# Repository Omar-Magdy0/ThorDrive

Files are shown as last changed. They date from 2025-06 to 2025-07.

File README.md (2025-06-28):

---
# ⚡ ThorDrive

A modular, open-source platform for developing **inverters**, **controllers**, and **embedded firmware** for electric vehicle applications.  
Built with robust engineering principles and driven by passion.

Maintained by **Omar Magdy** for the **Cairo University Eco Racing Team**.

---

## 🧠 Overview

ThorDrive implements a range of hardware and software solutions for electric drive systems.  
It includes:

- Custom inverters (multi-phase and bidirectional support)
- Firmware for Trapezoidal , FOC, SPWM, SVM, and advanced motor control
- Modular controllers and drivers
- Fully documented software and hardware stacks
- Design iterations built for real-world racing

---

## 🚀 Features

- ⚙️ **Multiple Inverter Designs**
- 🧾 **Well-documented Firmware** using Doxygen
- 💡 **Modular & Scalable Design** across generations
- 🛠️ **Interactive BOMs and Fabrication-Ready Gerbers**
- 🔧 **Configurable Build System** for firmware
- 💻 **Simulator & HIL Support**
- 🧪 **Validated by Real-World Team Use**

Specific features are documented in each design subfolder:

## 🛠️ Get Started

1. **Navigate to a Design Folder**  
   Visit:
   - `ThorDrive_FW/<DesignName_and_Version>/README.md`
   - `ThorDrive_HW/<DesignName_and_Version>/README.md`

2. **Build Software / Flash Firmware**  
   Follow platform-specific build instructions in each firmware README.

3. **Hardware Fabrication**  
   - Use provided **Gerber** files for PCB manufacturing.
   - Access **Interactive BOM** from each hardware directory.

---

## 📚 Documentation

- **Firmware Documentation (Doxygen)**  
  Inside:  
  `ThorDrive_FW/<DesignName_and_Version>/docs/index.html`

- **Hardware Documentation**  
  - Inverter: `ThorDrive_HW/<DesignName_and_Version>/Inverter/Docs/`
  - Controller: `ThorDrive_HW/<DesignName_and_Version>/Controller/Docs/`

---

## 📦 Installation

- Build your own firmware using the instructions in each firmware folder.
- Or, download the **precompiled binaries** from the design folders.
- Configure and flash using the README-provided instructions.

---

## 🧑‍💻 Used By

- 🏁 **Cairo University Eco Racing Team** https://cu-eco.org

---

## 📄 License

This project is open source.  
📌 **License**:  MIT

---

## 💬 Support

You can support the project by:

- Contributing firmware or hardware improvements
- Reviewing documentation and build systems
- Participating in issue tracking and pull requests
- Providing feedback based on hardware tests
- Become a sponsor
---

## 🤝 Sponsors

- 🐚 **Shell**
- ✈️ **EgyptAir**

---

## 📬 Contact

Maintainer: **Omar Magdy**  
📧 [omar.magdy.om.om@gmail.com](mailto:omar.magdy.om.om@gmail.com)

---

## 🏷️ Acknowledgements

- All engineers and contributors from the Cairo University Eco Racing Team

---

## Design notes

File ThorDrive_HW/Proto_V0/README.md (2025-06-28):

📁 `Controller`

# 🧠 BLDC Controller Board

---

## 🔁 Version & Overview

* **Version:** `v1.0`
* **Microcontroller:** `ATmega328P`
* **Designed using:** `KiCad`

The controller board enables BLDC motor control using ATmega328P and supports BEMF zero-crossing sensorless operation.

---

## 🔧 Features

* Sensorless BLDC drive (BEMF zero crossing)
* UART debugging
* Modular firmware architecture
* Supports 3.3V and 5V I/O
* Optimized for low-cost, compact embedded motor controllers
* Single-layer board with minimal top jumpers

#### Notes 
Remove onBoard Potentiometer if going to install external Potentiometer

---

## 🖼️ Hardware Preview
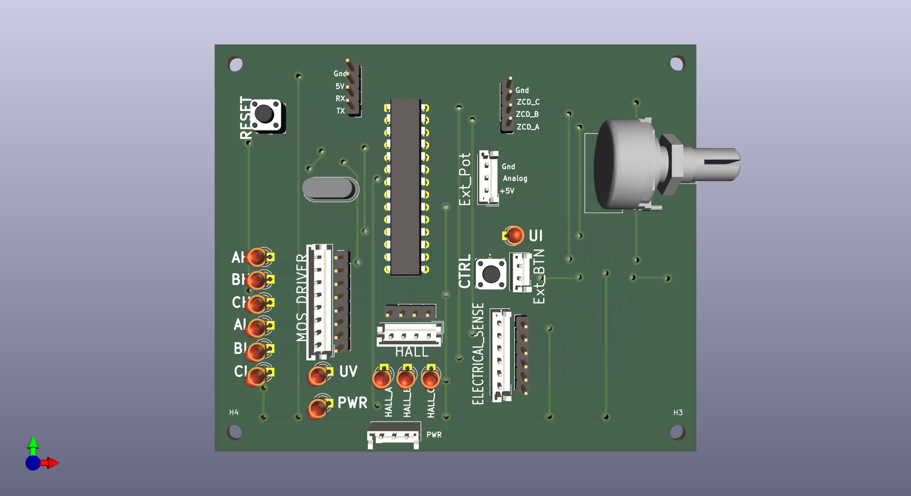
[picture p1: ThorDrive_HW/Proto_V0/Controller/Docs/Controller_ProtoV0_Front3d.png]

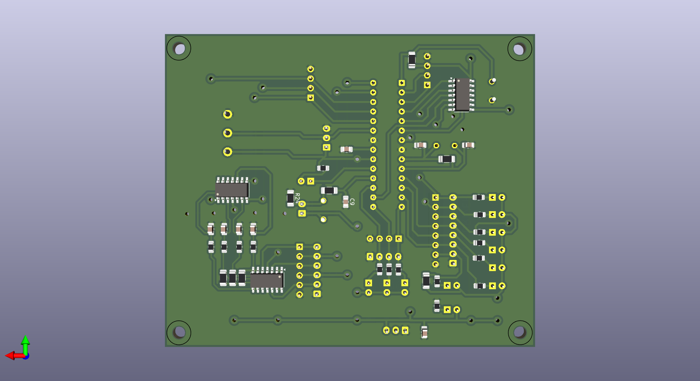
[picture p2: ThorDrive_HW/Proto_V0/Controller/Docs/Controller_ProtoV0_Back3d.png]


---

## 📁 Documentation

| Type | Path |
| --- | --- |
| 🧩 3D Model | `./Controller/Docs/*.step` |
| 📝 Schematic | `./Controller/Docs/*.pdf`  |
| 📂 Design Files | `./Controller` |

### 🌐 Embedded 3D Viewer (STEP)

Try with: [https://3dviewer.net/](https://3dviewer.net/)
Upload: [`./Controller/Docs/*.step`](./Docs)

---

📁 `Inverter`

# ⚡ BLDC Inverter Board

---

## 🔁 Version & Overview

* **Version:** `v1.0`
* **Designed using:** `KiCad`
* **Power Rating:** `2KW+`
* **MOSFET Driver:** `IR2130`

---

## 🔧 Features

### ✅ Phase Voltage Feedback

* Each phase is conditioned via:

  $V_{cond} = V_{phase-ground} \times \left(\frac{2.2k}{49.2k}\right)$

* Filtered with **80kHz low-pass**

* Calibrate as needed due to resistor tolerances

### ✅ Line Current Feedback (ACS712-30A)

* For Phase A & B:

  $V_{cond} = \left( I_{line} \times 66\text{mV} + 2.5 \right) \times \left(\frac{5.1k}{15.1k}\right)$

* Filtered with **80kHz low-pass**

* Calibrate as needed due to resistor tolerances

### ✅ &#x20;General Specs

* 3.3V signal compatible
* Switching frequency up to **20kHz**
* Driver with built-in **dead time** (IR2130)
* 🌡️ **Thermal Management**: Adequate spacing for heat sinks
* Single-layer board with minimal top jumpers

---

## 🖼️ Hardware Preview

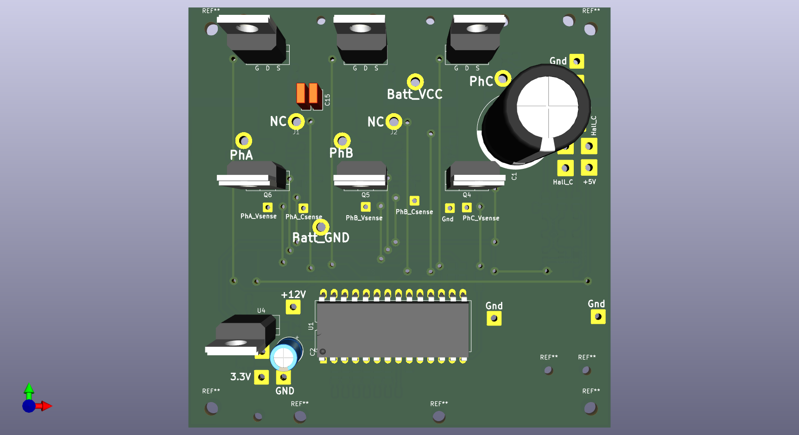
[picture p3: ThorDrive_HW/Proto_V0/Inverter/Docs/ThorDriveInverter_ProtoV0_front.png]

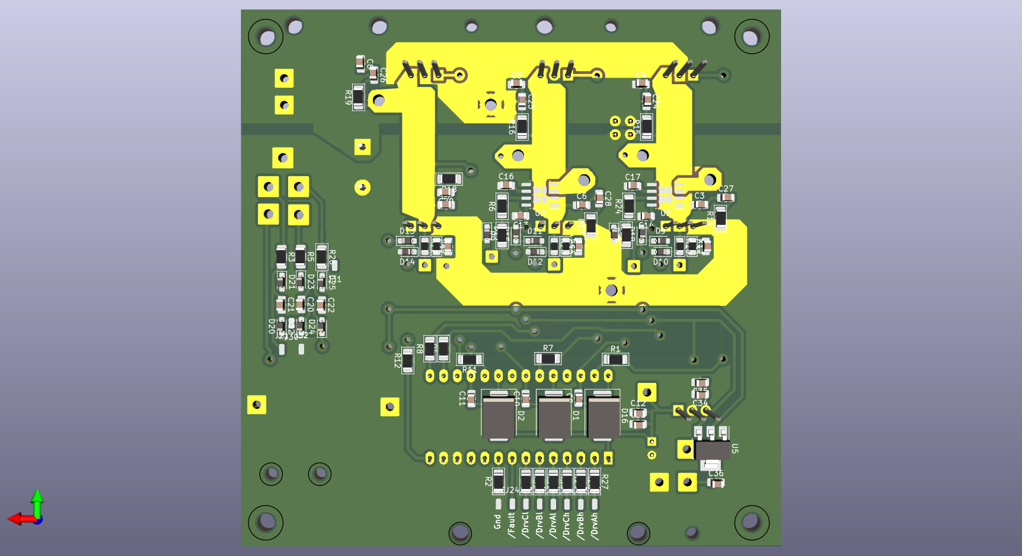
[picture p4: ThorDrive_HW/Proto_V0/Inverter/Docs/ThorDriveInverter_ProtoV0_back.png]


---

## 📁 Documentation

| Type | Path |
| --- | --- |
| 🧩 3D Model | `./Inverter/Docs/*.step` |
| 📝 Schematic | `./Inverter/Docs/*.pdf`  |
| 📂 Design Files | `./Inverter` |

### 🌐 Embedded 3D Viewer (STEP)

Try with: [https://3dviewer.net/](https://3dviewer.net/)
Upload: [`Docs/*.step`](./Docs)

---

## 🔌 Connector Layout & Wiring
Proper connector pin labeling is essential for integration with other subsystems (sensors, MCU, battery, etc.). Images and pinout illustrations will help ensure correct assembly.

### 📷 Visual Reference
 #### 📍 Connector Numbering Reference
<!-- Replace with your actual images -->
**JST**
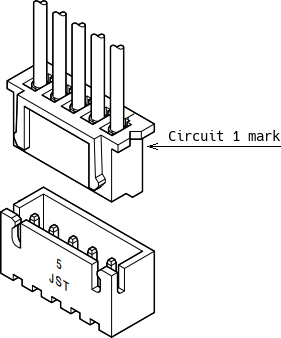
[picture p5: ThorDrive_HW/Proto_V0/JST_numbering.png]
JST Numbering Reference


**Molex**
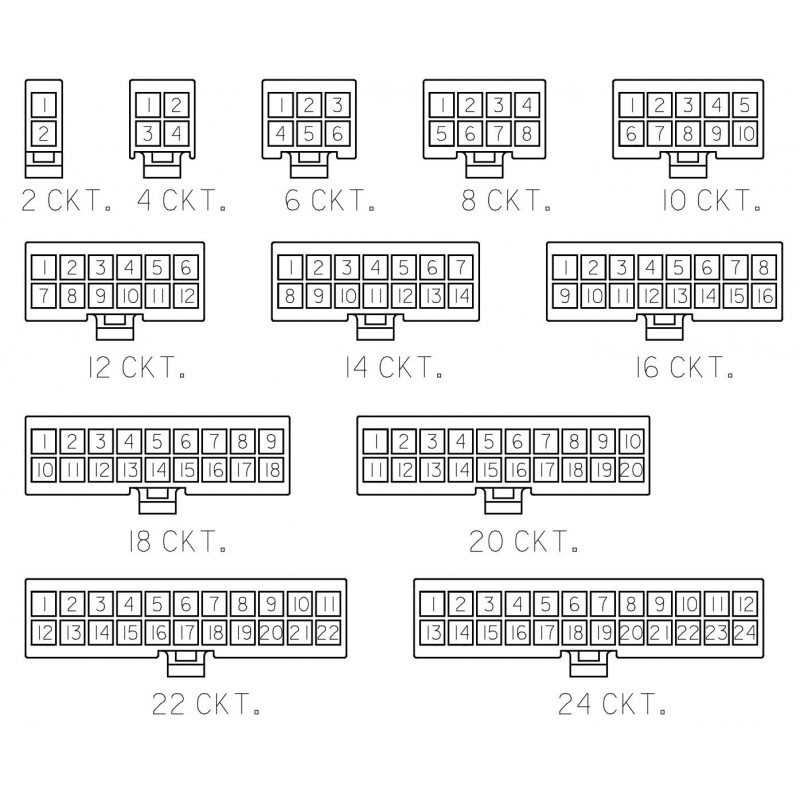
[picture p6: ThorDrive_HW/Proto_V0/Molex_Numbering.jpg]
Molex Numbering Reference


🔌 Sample Harness:  

Controller_Board
---

## 📜 License

This project is licensed under the **MIT License**.
---

## 📬 Contact

Maintainer: **Omar Magdy**
📧 [omar.magdy.om.om@gmail.com](mailto:omar.magdy.om.om@gmail.com)

---

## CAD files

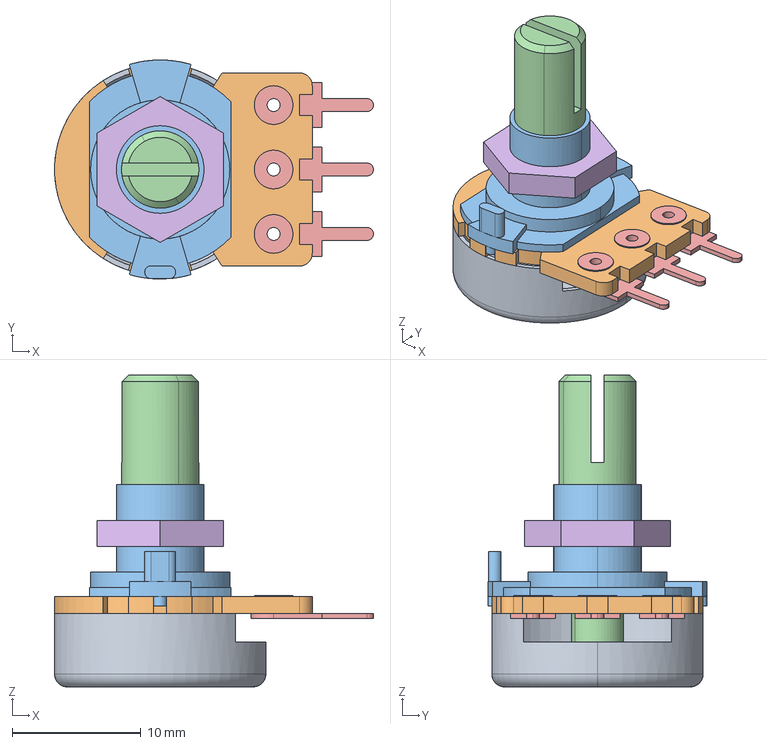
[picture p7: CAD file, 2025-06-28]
ThorDrive_HW/Proto_V0/Controller/LibMain/3d/POT.stp
24.8 x 17.0 x 24.2 mm

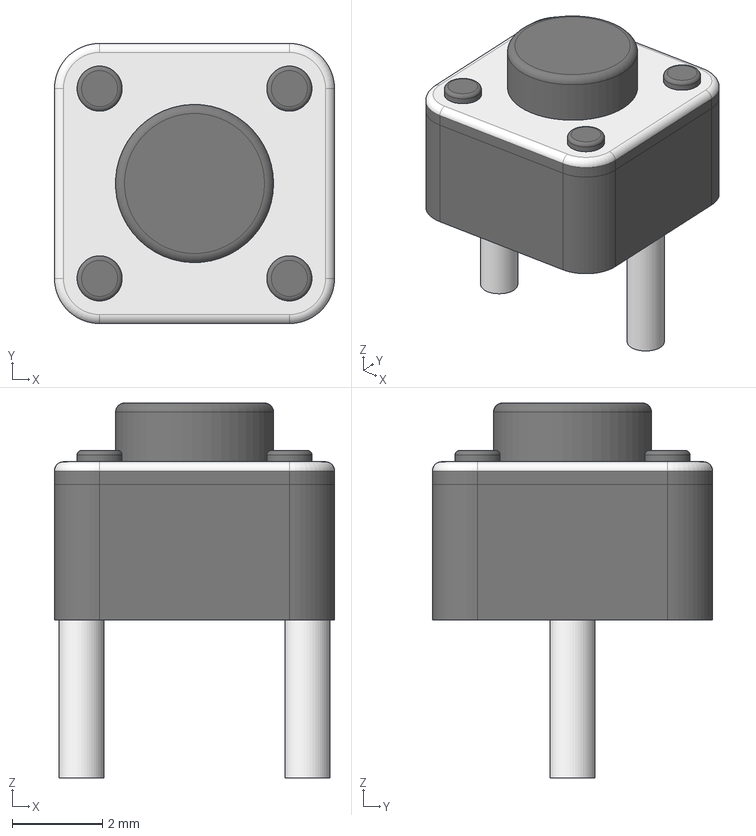
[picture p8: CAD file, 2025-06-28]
ThorDrive_HW/Proto_V0/Controller/LibMain/3d/boton.step
6.20 x 6.20 x 8.30 mm

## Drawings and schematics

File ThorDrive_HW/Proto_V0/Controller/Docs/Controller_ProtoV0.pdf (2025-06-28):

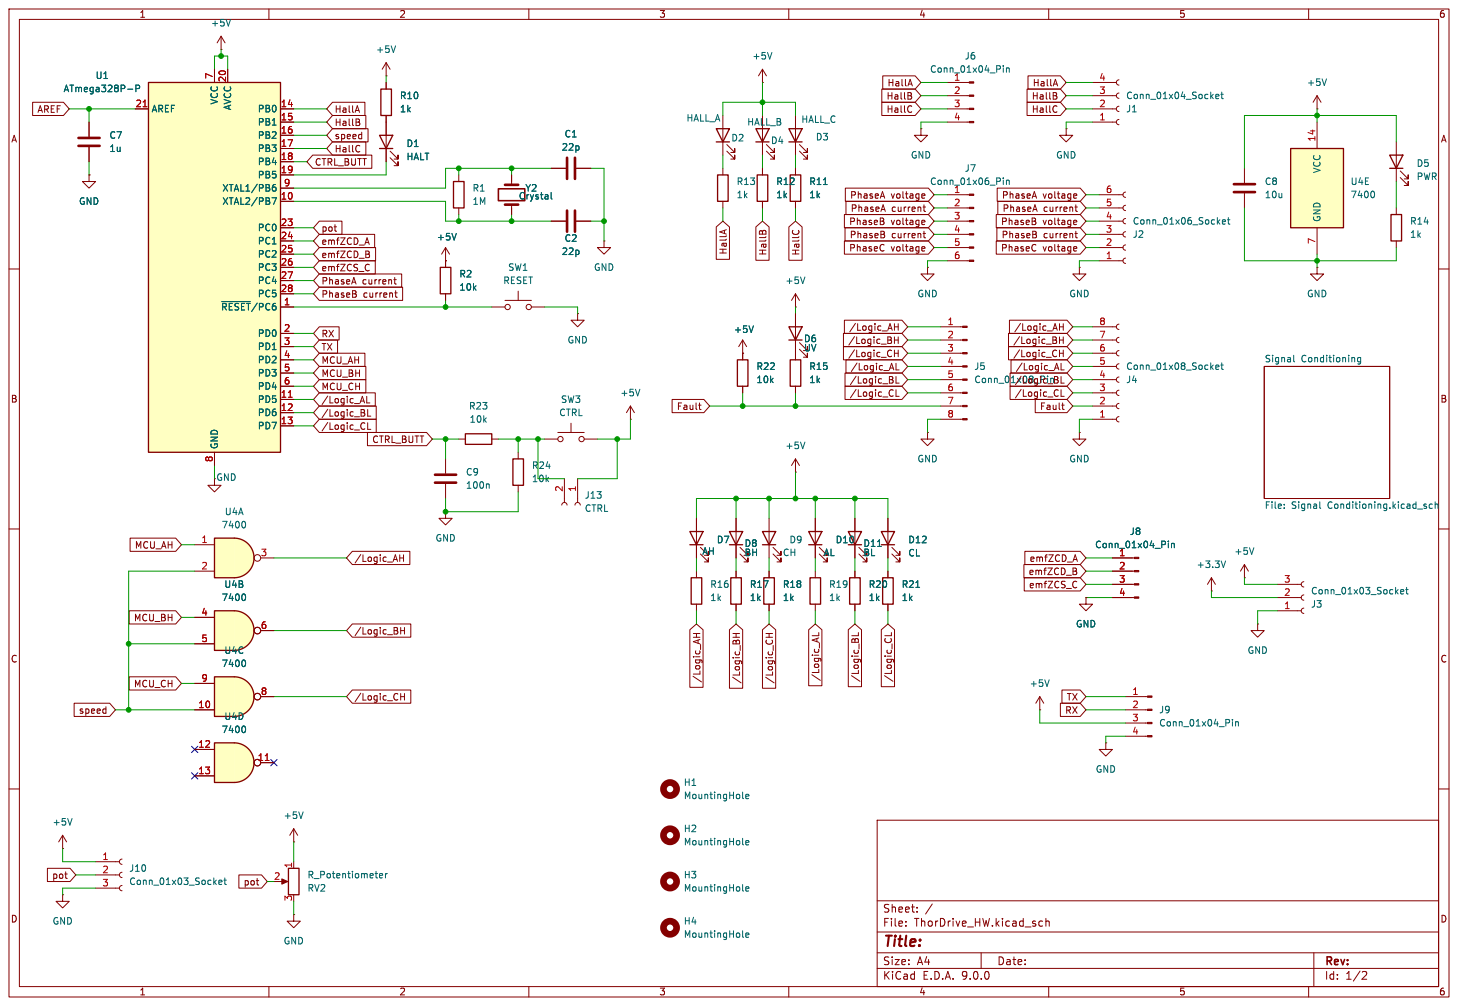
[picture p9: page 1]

HallC
PhaseC voltage PhaseB current CTRL_BUTT

J4Conn_01x08_Socket +5V H3 MountingHole H1 MountingHole H2 MountingHole H4 MountingHole

Signal Conditioning File: Signal Conditioning.kicad_sch

Id: 1/2 Title: File: ThorDrive_HW.kicad_sch Sheet: /

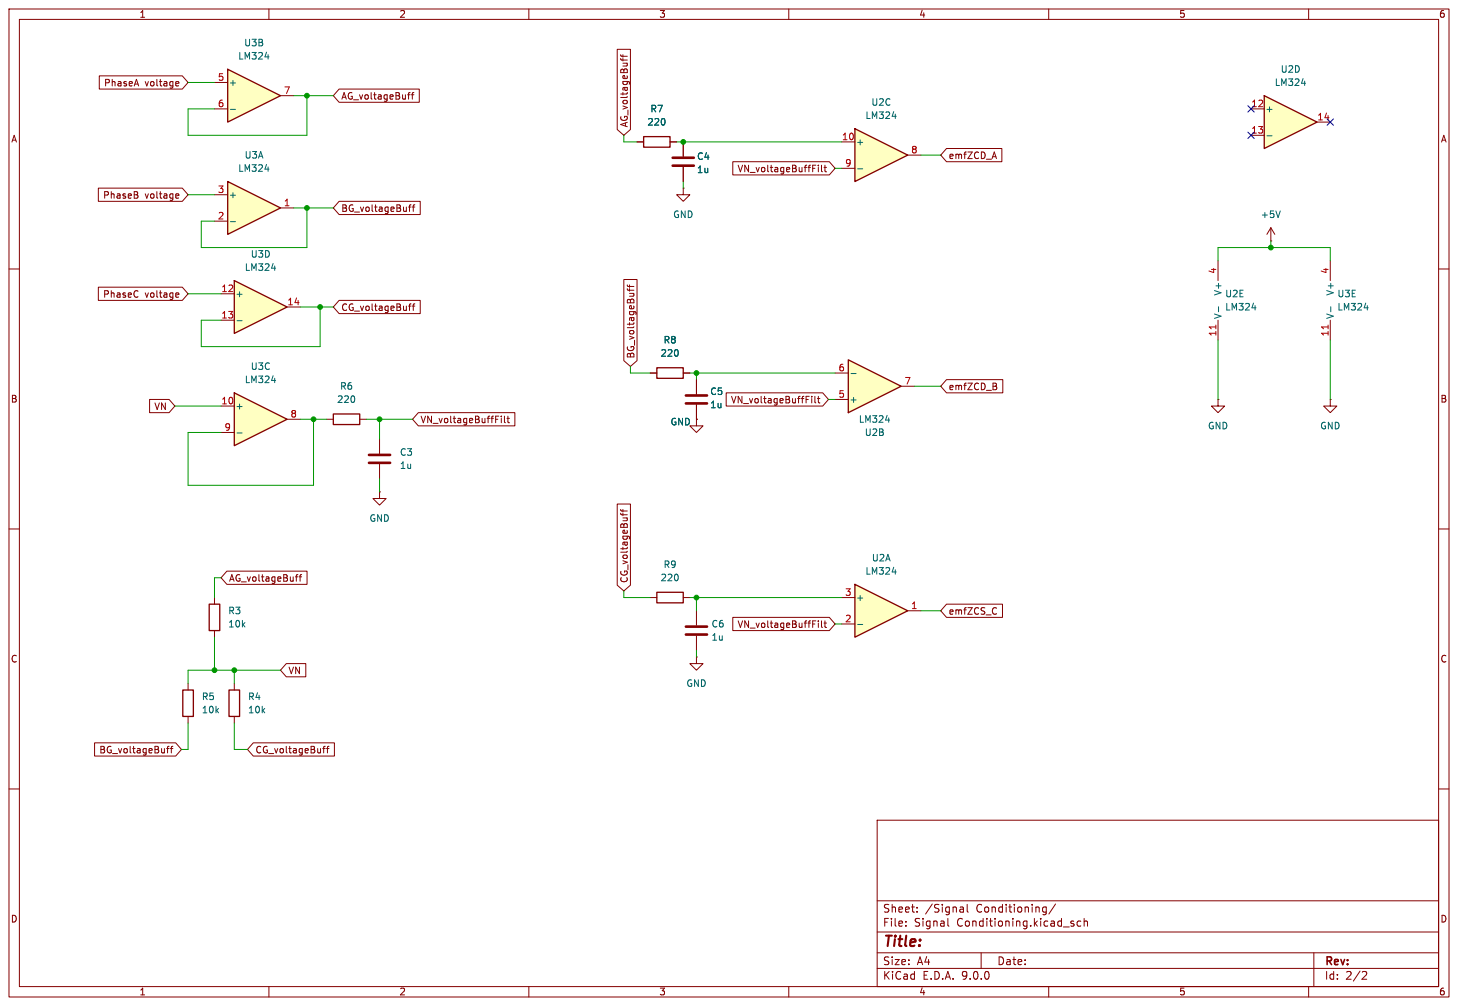
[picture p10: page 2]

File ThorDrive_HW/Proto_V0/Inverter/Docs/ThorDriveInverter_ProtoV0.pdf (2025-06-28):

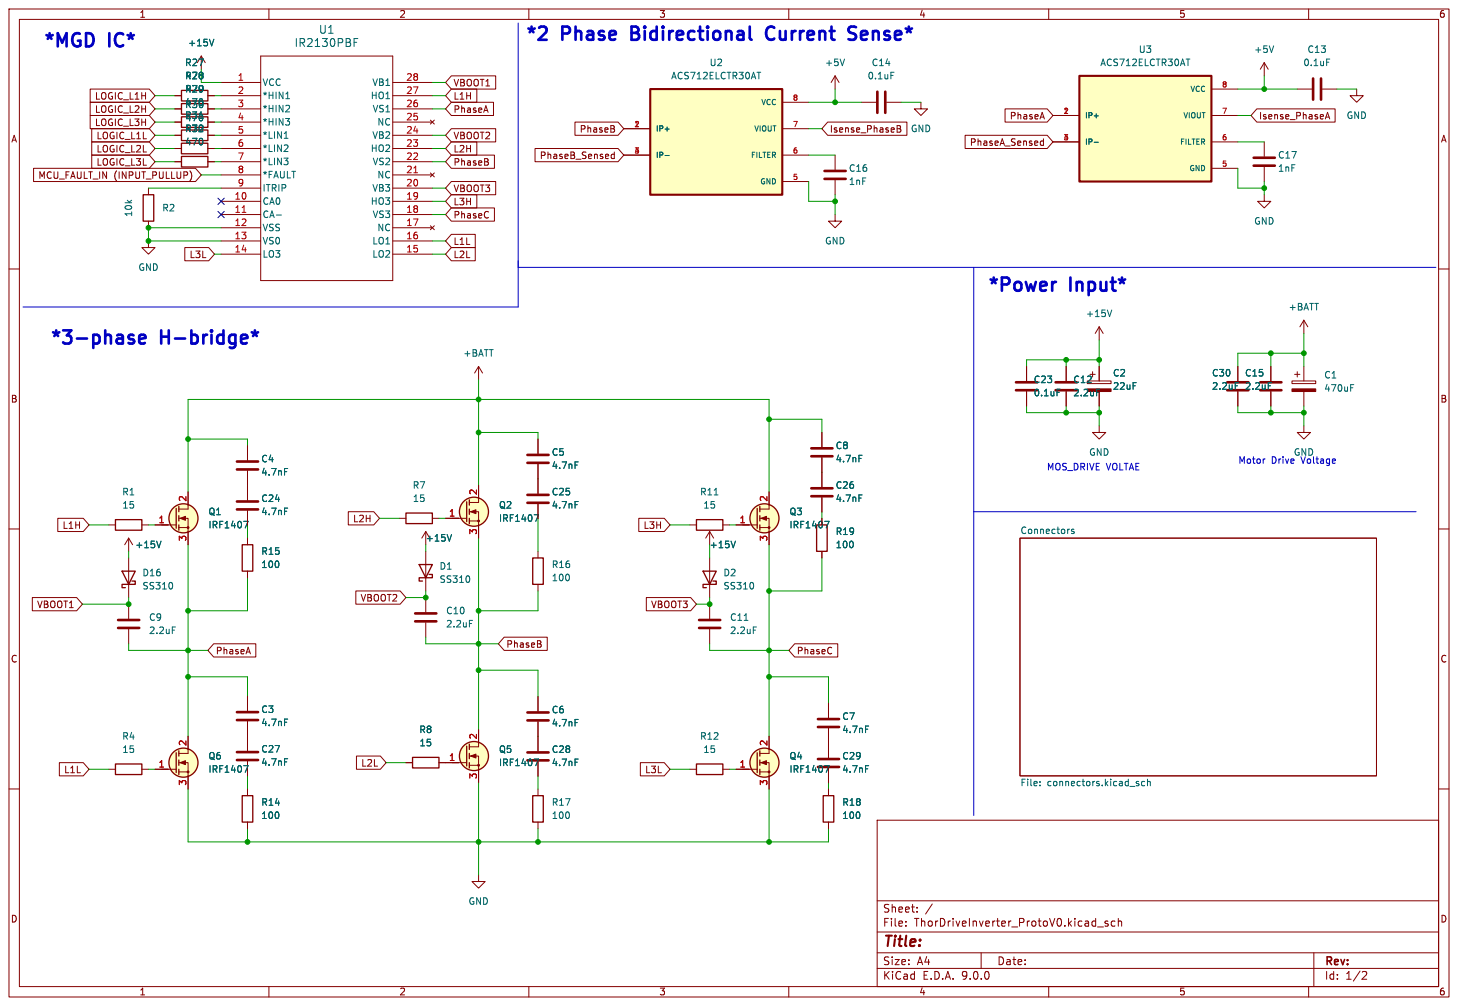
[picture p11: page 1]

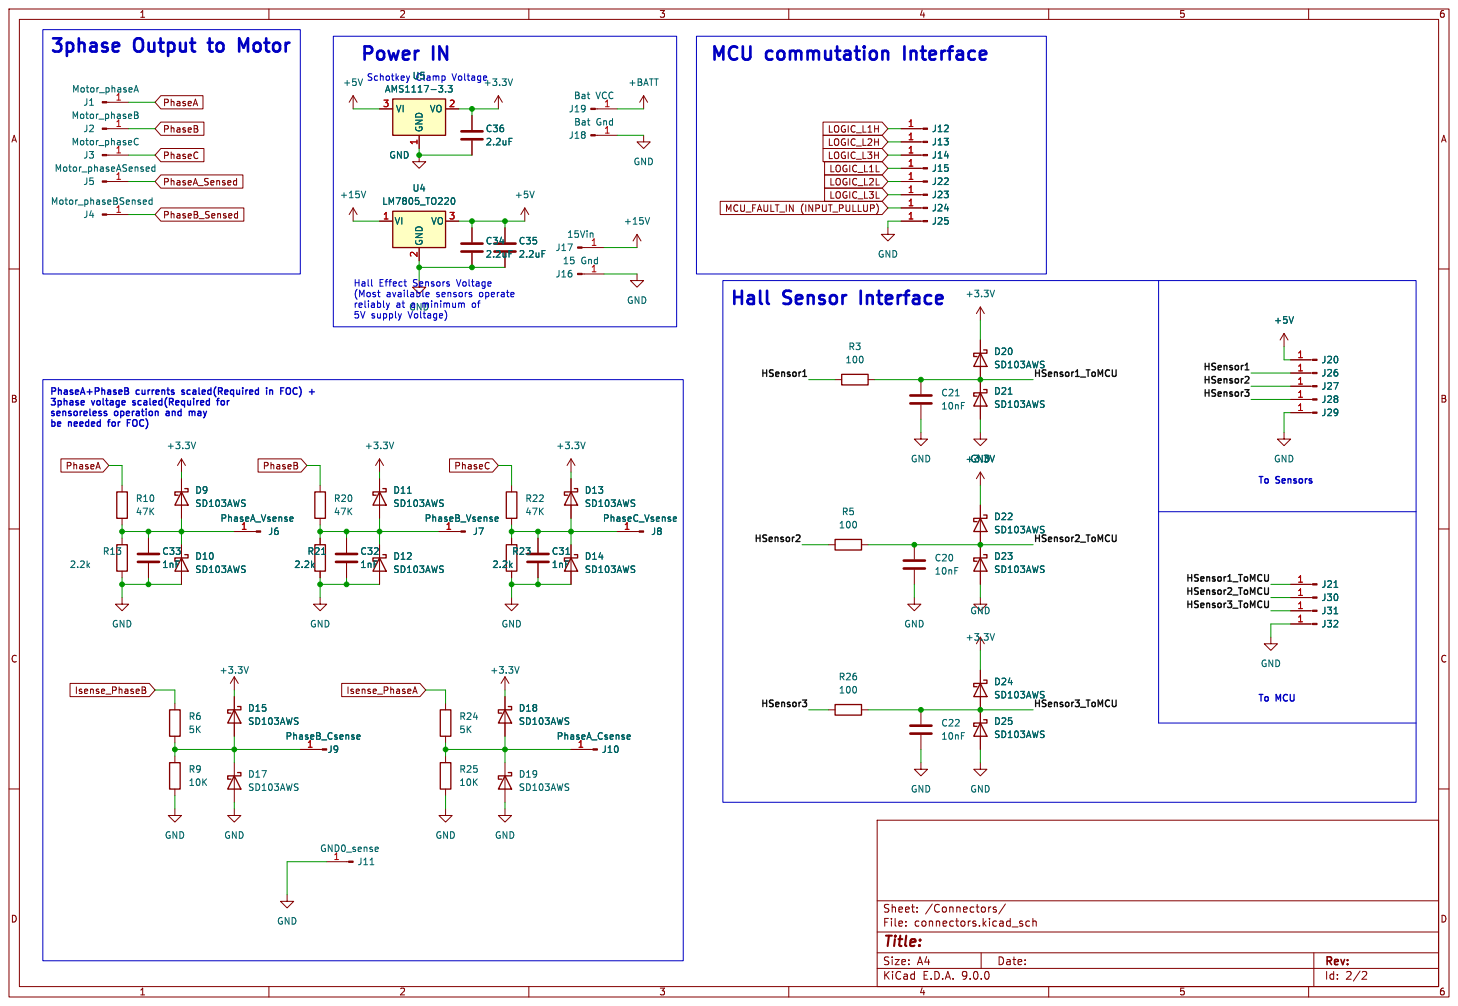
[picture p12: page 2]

To MCU 3phase Output to Motor

Hall Effect Sensors Voltage

Id: 2/2 Title: File: connectors.kicad_sch Sheet: /Connectors/ GND

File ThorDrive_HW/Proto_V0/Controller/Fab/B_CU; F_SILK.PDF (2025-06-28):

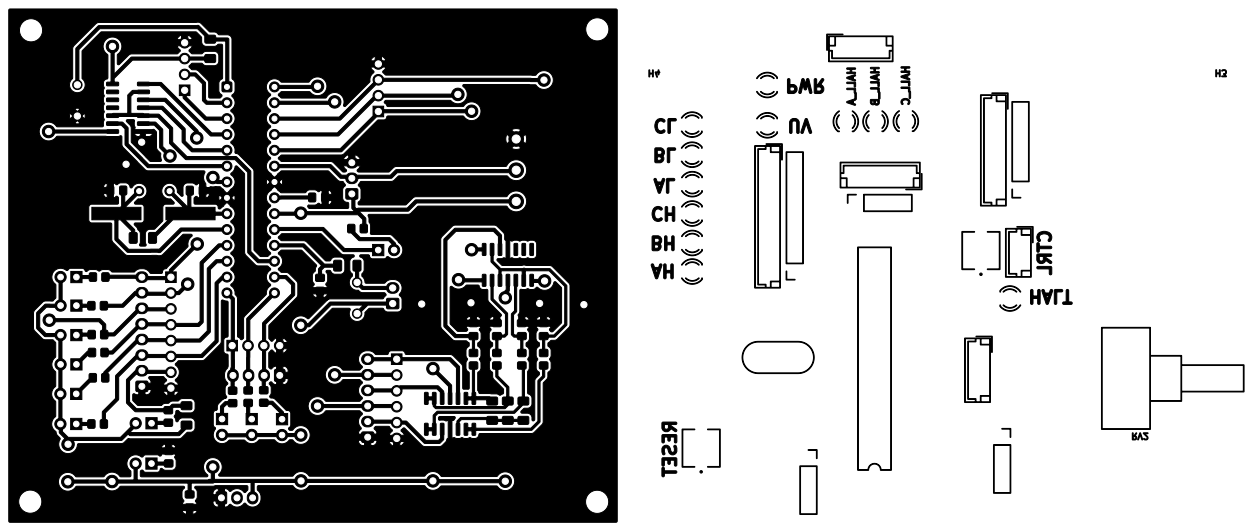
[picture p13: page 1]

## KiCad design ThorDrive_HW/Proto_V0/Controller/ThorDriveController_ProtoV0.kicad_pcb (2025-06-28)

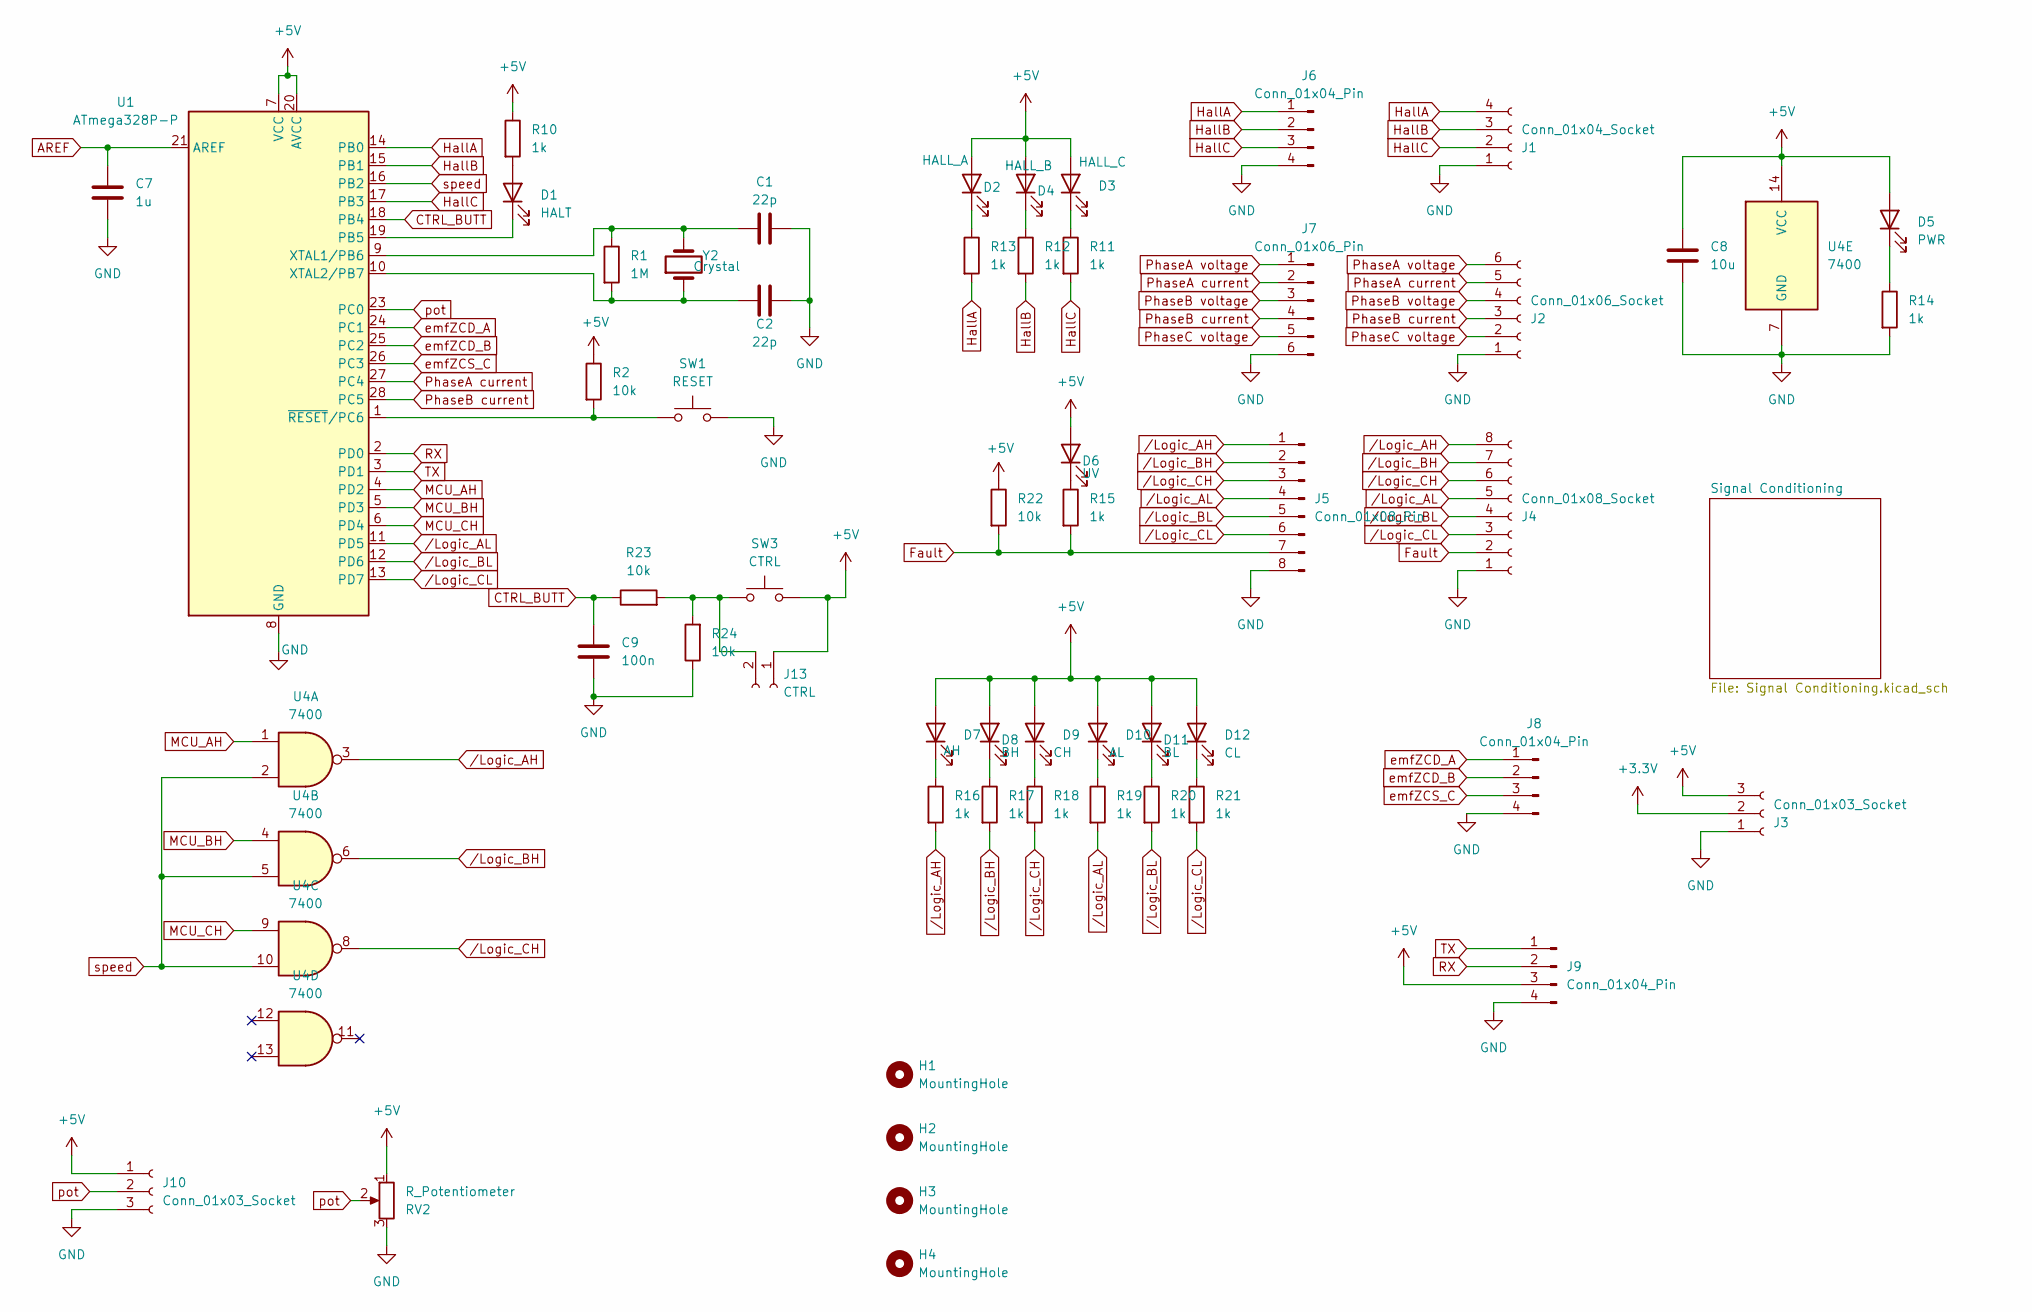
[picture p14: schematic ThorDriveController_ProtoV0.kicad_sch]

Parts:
C1, C2: 22p; C_0805_2012Metric_Pad1.18x1.45mm_HandSolder
C7: 1u; C_0805_2012Metric_Pad1.18x1.45mm_HandSolder
C8: 10u; C_0805_2012Metric_Pad1.18x1.45mm_HandSolder
C9: 100n; C_0805_2012Metric_Pad1.18x1.45mm_HandSolder
D1: HALT; LED_D3.0mm
D2: HALL_A; LED_D3.0mm
D3: HALL_C; LED_D3.0mm
D4: HALL_B; LED_D3.0mm
D5: PWR; LED_D3.0mm
D6: UV; LED_D3.0mm
D7: AH; LED_D3.0mm
D8: BH; LED_D3.0mm
D9: CH; LED_D3.0mm
D10: AL; LED_D3.0mm
D11: BL; LED_D3.0mm
D12: CL; LED_D3.0mm
H1, H2, H3, H4: MountingHole; MountingHole_3.2mm_M3
J1: Conn_01x04_Socket; JST_EH_B4B-EH-A_1x04_P2.50mm_Vertical
J2: Conn_01x06_Socket; JST_EH_B6B-EH-A_1x06_P2.50mm_Vertical
J3, J10: Conn_01x03_Socket; JST_EH_B3B-EH-A_1x03_P2.50mm_Vertical
J4: Conn_01x08_Socket; JST_EH_B8B-EH-A_1x08_P2.50mm_Vertical
J5: Conn_01x08_Pin; PinHeader_1x08_P2.54mm_Vertical
J6, J8, J9: Conn_01x04_Pin; PinHeader_1x04_P2.54mm_Vertical
J7: Conn_01x06_Pin; PinHeader_1x06_P2.54mm_Vertical
J13: CTRL; JST_EH_B2B-EH-A_1x02_P2.50mm_Vertical
R1: 1M; R_1206_3216Metric_Pad1.30x1.75mm_HandSolder
R2, R22, R23, R24: 10k; R_1206_3216Metric_Pad1.30x1.75mm_HandSolder
R10, R11, R12, R13, R14, R15, R16, R17, R18, R19, R20, R21: 1k; R_0805_2012Metric_Pad1.20x1.40mm_HandSolder
RV2: R_Potentiometer; Potentiometer_Piher_T-16H_Single_Horizontal
SW1: RESET; SW_BUTT-2
SW3: CTRL; SW_BUTT-2
U1: ATmega328P-P; DIP-28_W7.62mm
U4: 7400; SOIC-14_3.9x8.7mm_P1.27mm
Y2: Crystal; Crystal_HC49-4H_Vertical

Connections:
+3.3V: J3.2
+5V: C8.1, D2.2 (A), D3.2 (A), D4.2 (A), D5.2 (A), D6.2 (A), D7.2 (A), D8.2 (A), D9.2 (A), D10.2 (A), D11.2 (A), D12.2 (A), J3.3, J9.3, J10.1, J13.1, R2.1, R10.1, R22.1, RV2.1, SW3.2, U1.7 (VCC), U1.20 (AVCC), U4.14 (VCC); also elsewhere on the board
AREF: C7.1, U1.21 (AREF)
CTRL_BUTT: C9.1, R23.1, U1.18 (PB4)
Fault: J4.2, J5.7, R15.2, R22.2
GND: C1.2, C2.2, C7.2, C8.2, C9.2, J1.1, J2.1, J3.1, J4.1, J5.8, J6.4, J7.6, J8.4, J9.4, J10.3, R14.2, R24.1, RV2.3, SW1.2, U1.8 (GND), U1.22 (GND), U4.7 (GND); also elsewhere on the board
HallA: J1.4, J6.1, R13.2, U1.14 (PB0)
HallB: J1.3, J6.2, R12.2, U1.15 (PB1)
HallC: J1.2, J6.3, R11.2, U1.17 (PB3)
MCU_AH: U1.4 (PD2), U4.1
MCU_BH: U1.5 (PD3), U4.4
MCU_CH: U1.6 (PD4), U4.9
unnamed: D1.2 (A), R10.2
unnamed: D1.1 (K), U1.19 (PB5)
unnamed: D2.1 (K), R13.1
unnamed: D3.1 (K), R11.1
unnamed: D4.1 (K), R12.1
unnamed: D5.1 (K), R14.1
unnamed: D6.1 (K), R15.1
unnamed: D7.1 (K), R16.1
unnamed: D8.1 (K), R17.1
unnamed: D9.1 (K), R18.1
unnamed: D10.1 (K), R19.1
unnamed: D11.1 (K), R20.1
unnamed: D12.1 (K), R21.1
unnamed: J13.2, R23.2, R24.2, SW3.1
unnamed: C1.1, R1.1, U1.9 (XTAL1/PB6), Y2.2
unnamed: C2.1, R1.2, U1.10 (XTAL2/PB7), Y2.1
unnamed: R2.2, SW1.1, U1.1 (~RESET/PC6)
PhaseA current: J2.5, J7.2, U1.27 (PC4)
PhaseA voltage: J2.6, J7.1; also elsewhere on the board
PhaseB current: J2.3, J7.4, U1.28 (PC5)
PhaseB voltage: J2.4, J7.3; also elsewhere on the board
PhaseC voltage: J2.2, J7.5; also elsewhere on the board
RX: J9.2, U1.2 (PD0)
TX: J9.1, U1.3 (PD1)
emfZCD_A: J8.1, U1.24 (PC1); also elsewhere on the board
emfZCD_B: J8.2, U1.25 (PC2); also elsewhere on the board
emfZCS_C: J8.3, U1.26 (PC3); also elsewhere on the board
pot: J10.2, RV2.2, U1.23 (PC0)
speed: U1.16 (PB2), U4.2, U4.5, U4.10
/Logic_AH: J4.8, J5.1, R16.2, U4.3
/Logic_AL: J4.5, J5.4, R19.2, U1.11 (PD5)
/Logic_BH: J4.7, J5.2, R17.2, U4.6
/Logic_BL: J4.4, J5.5, R20.2, U1.12 (PD6)
/Logic_CH: J4.6, J5.3, R18.2, U4.8
/Logic_CL: J4.3, J5.6, R21.2, U1.13 (PD7)

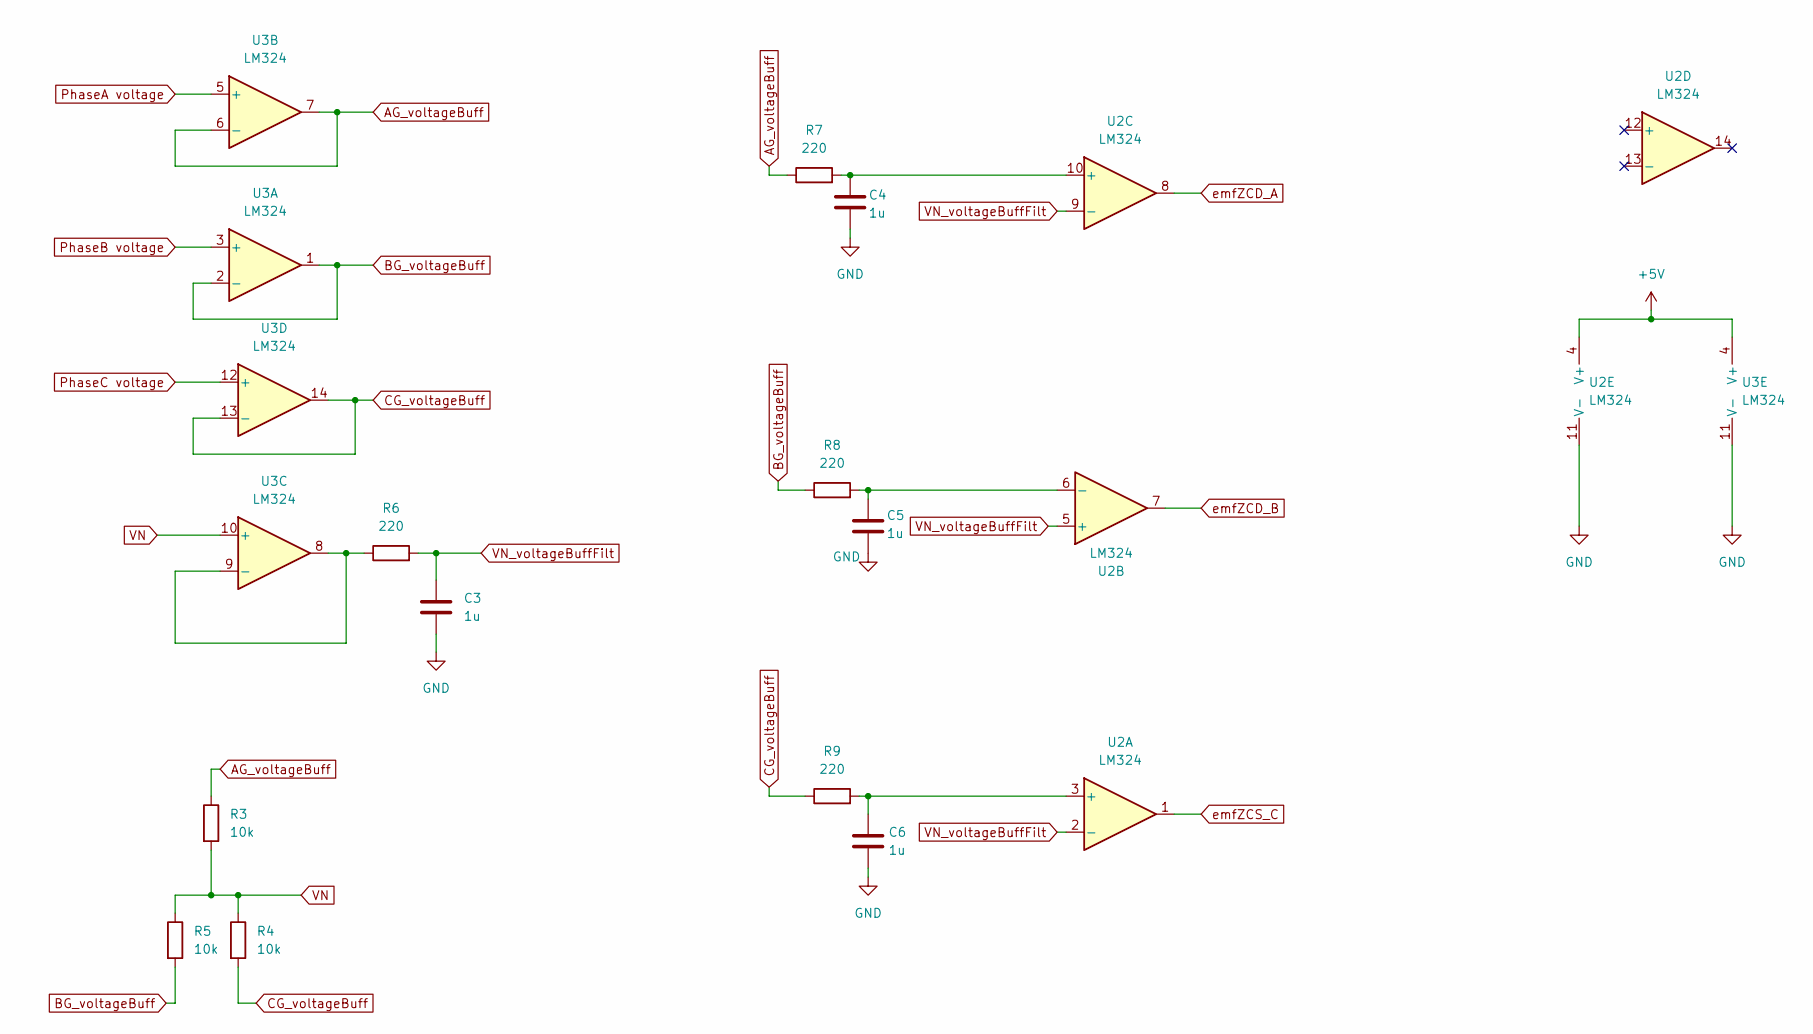
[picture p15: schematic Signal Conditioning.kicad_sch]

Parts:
C3, C4, C5, C6: 1u; C_0805_2012Metric_Pad1.18x1.45mm_HandSolder
R3, R4, R5: 10k; R_1206_3216Metric_Pad1.30x1.75mm_HandSolder
R6, R7, R8, R9: 220; R_0805_2012Metric_Pad1.20x1.40mm_HandSolder
U2, U3: LM324; SOIC-14_3.9x8.7mm_P1.27mm

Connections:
+5V: U2.4 (V+), U3.4 (V+); also elsewhere on the board
AG_voltageBuff: R3.1, R7.1, U3.6 (-), U3.7
BG_voltageBuff: R5.2, R8.1, U3.1, U3.2 (-)
CG_voltageBuff: R4.2, R9.1, U3.13 (-), U3.14
GND: C3.2, C4.2, C5.2, C6.2, U2.11 (V-), U3.11 (V-); also elsewhere on the board
unnamed: C6.1, R9.2, U2.3 (+)
unnamed: C5.1, R8.2, U2.6 (-)
unnamed: C4.1, R7.2, U2.10 (+)
unnamed: R6.1, U3.8, U3.9 (-)
PhaseA voltage: U3.5 (+); also elsewhere on the board
PhaseB voltage: U3.3 (+); also elsewhere on the board
PhaseC voltage: U3.12 (+); also elsewhere on the board
VN: R3.2, R4.1, R5.1, U3.10 (+)
VN_voltageBuffFilt: C3.1, R6.2, U2.2 (-), U2.5 (+), U2.9 (-)
emfZCD_A: U2.8; also elsewhere on the board
emfZCD_B: U2.7; also elsewhere on the board
emfZCS_C: U2.1; also elsewhere on the board

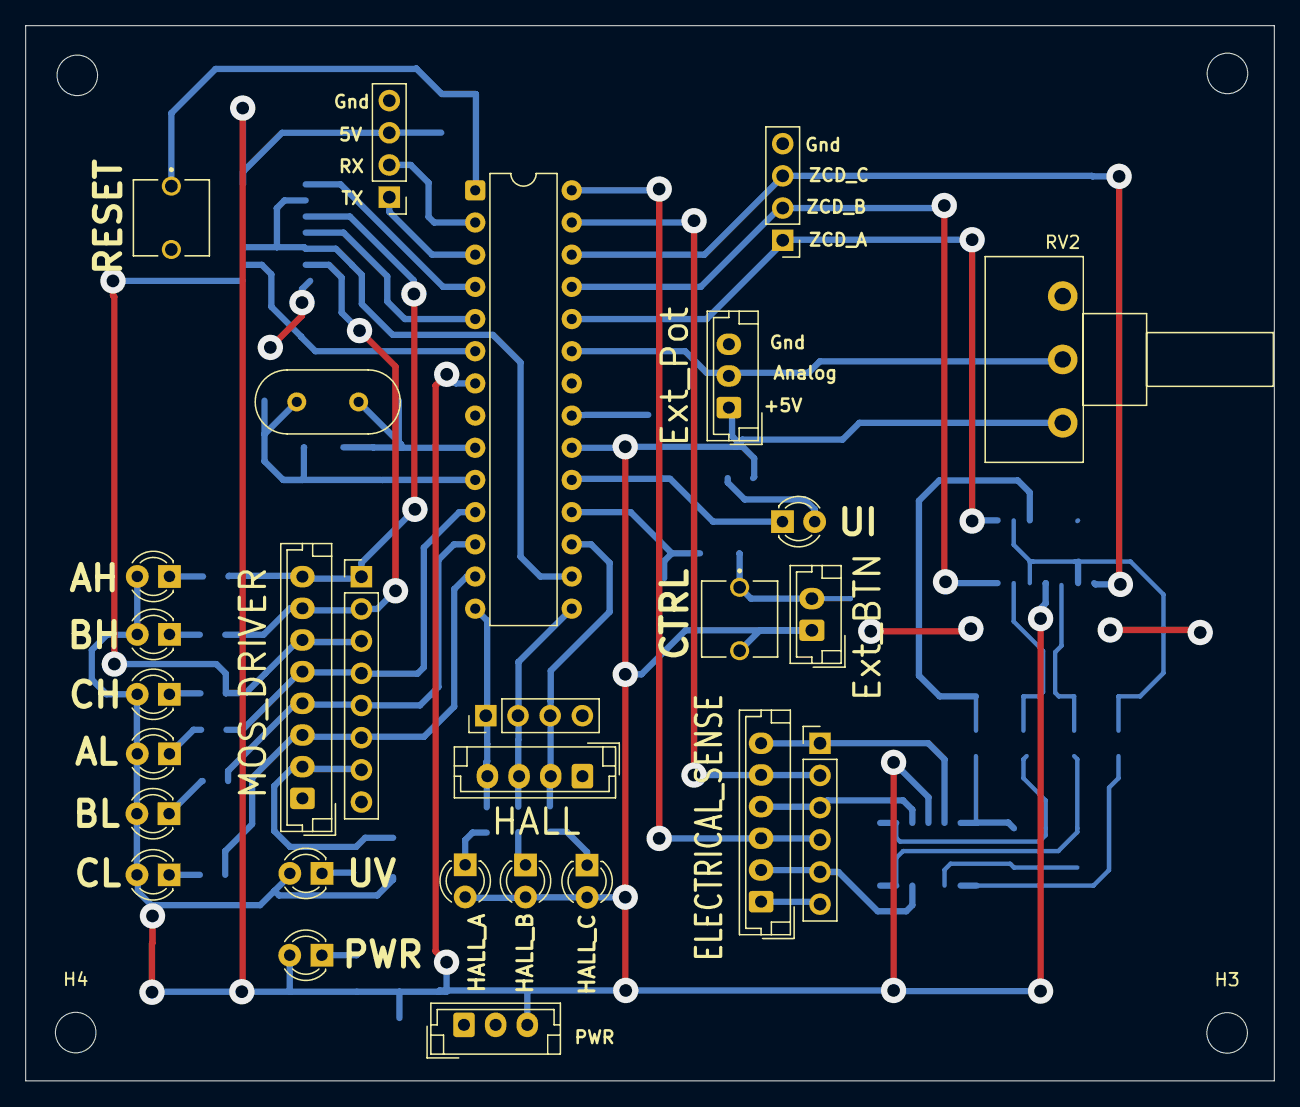
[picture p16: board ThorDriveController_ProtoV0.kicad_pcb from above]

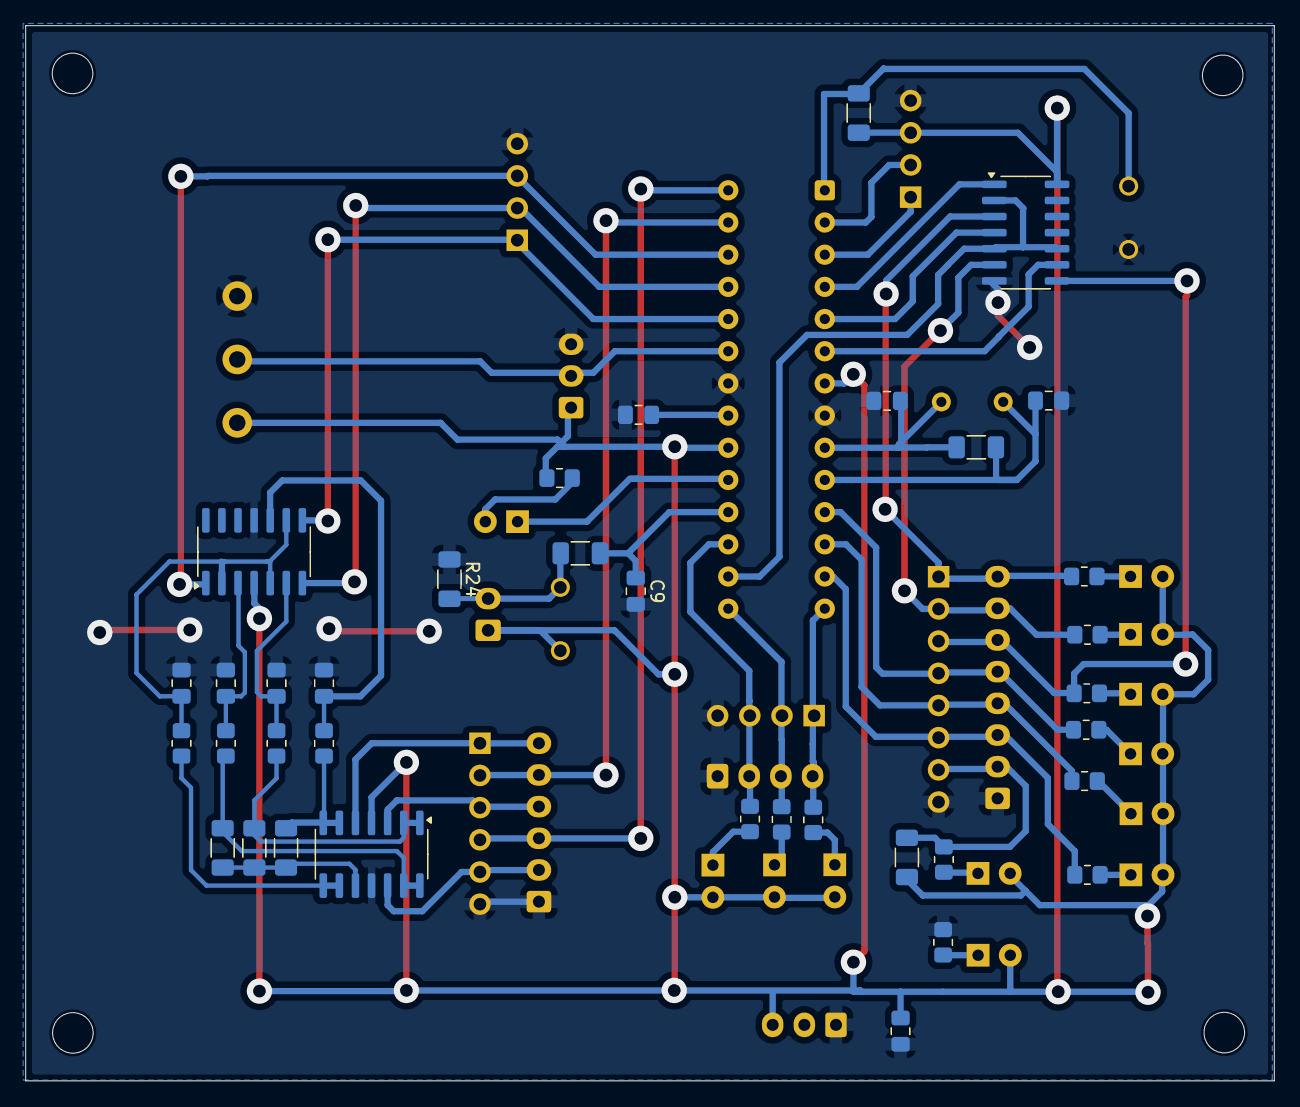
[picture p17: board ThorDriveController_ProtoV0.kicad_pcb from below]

Board: 2 copper layers, 98.5 x 83.3 mm, 68 parts (36 on the bottom side), 55 nets.

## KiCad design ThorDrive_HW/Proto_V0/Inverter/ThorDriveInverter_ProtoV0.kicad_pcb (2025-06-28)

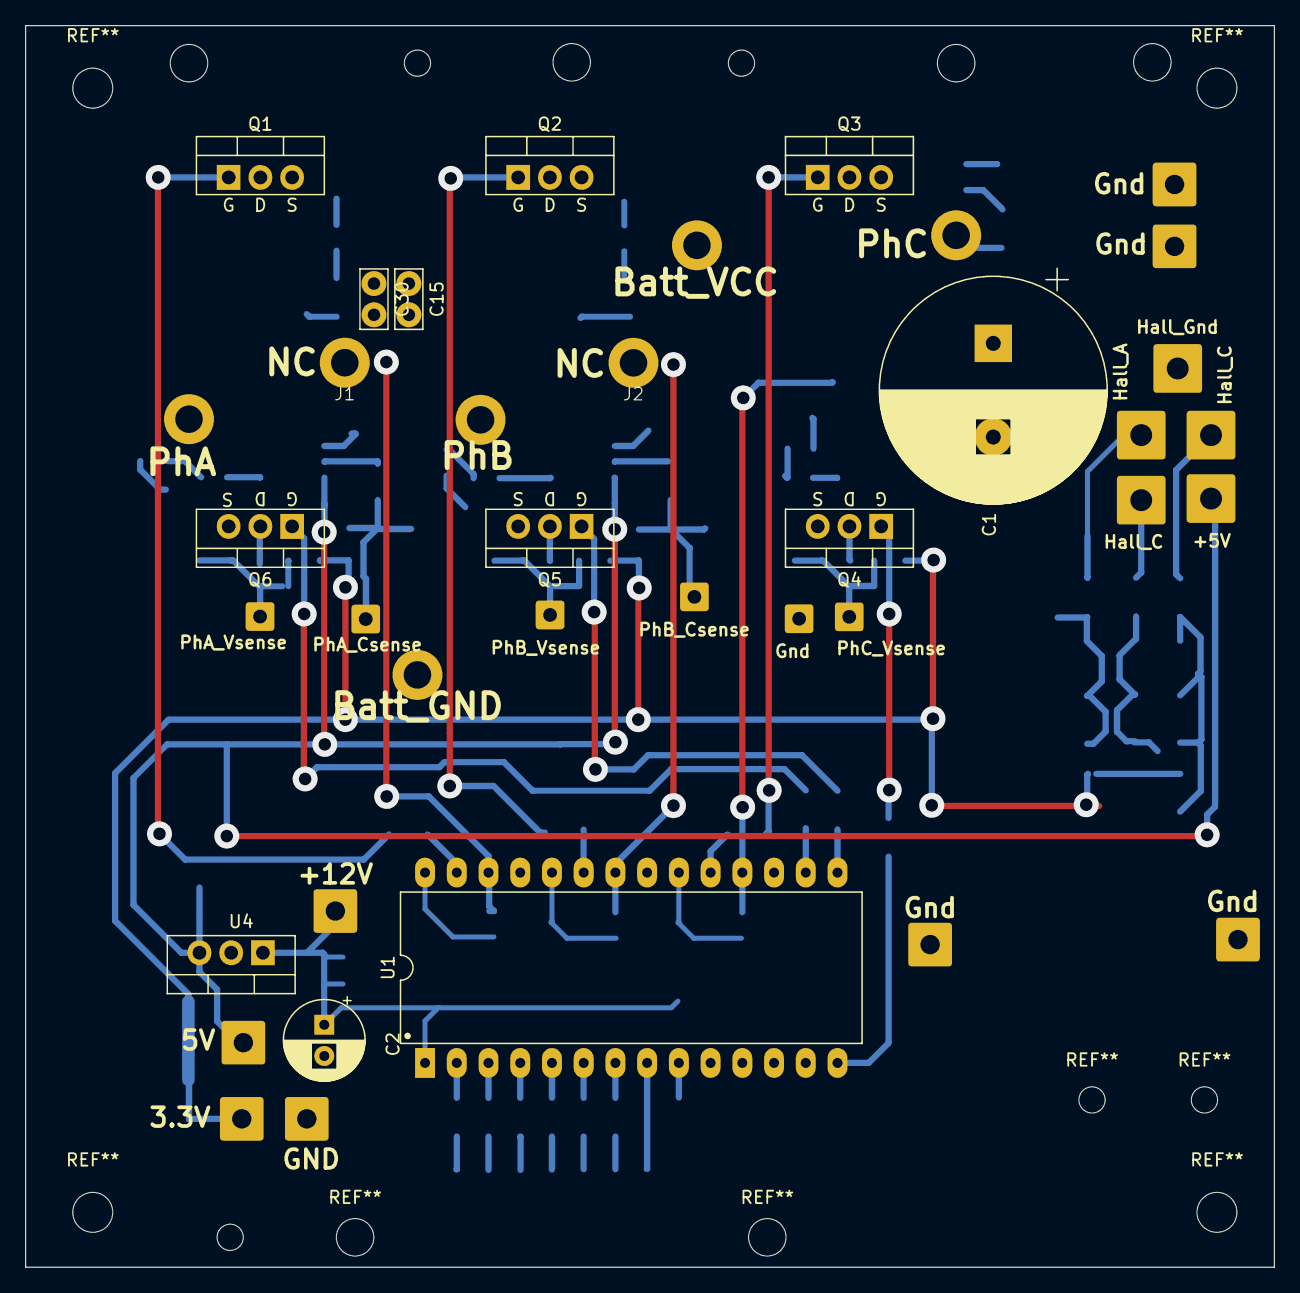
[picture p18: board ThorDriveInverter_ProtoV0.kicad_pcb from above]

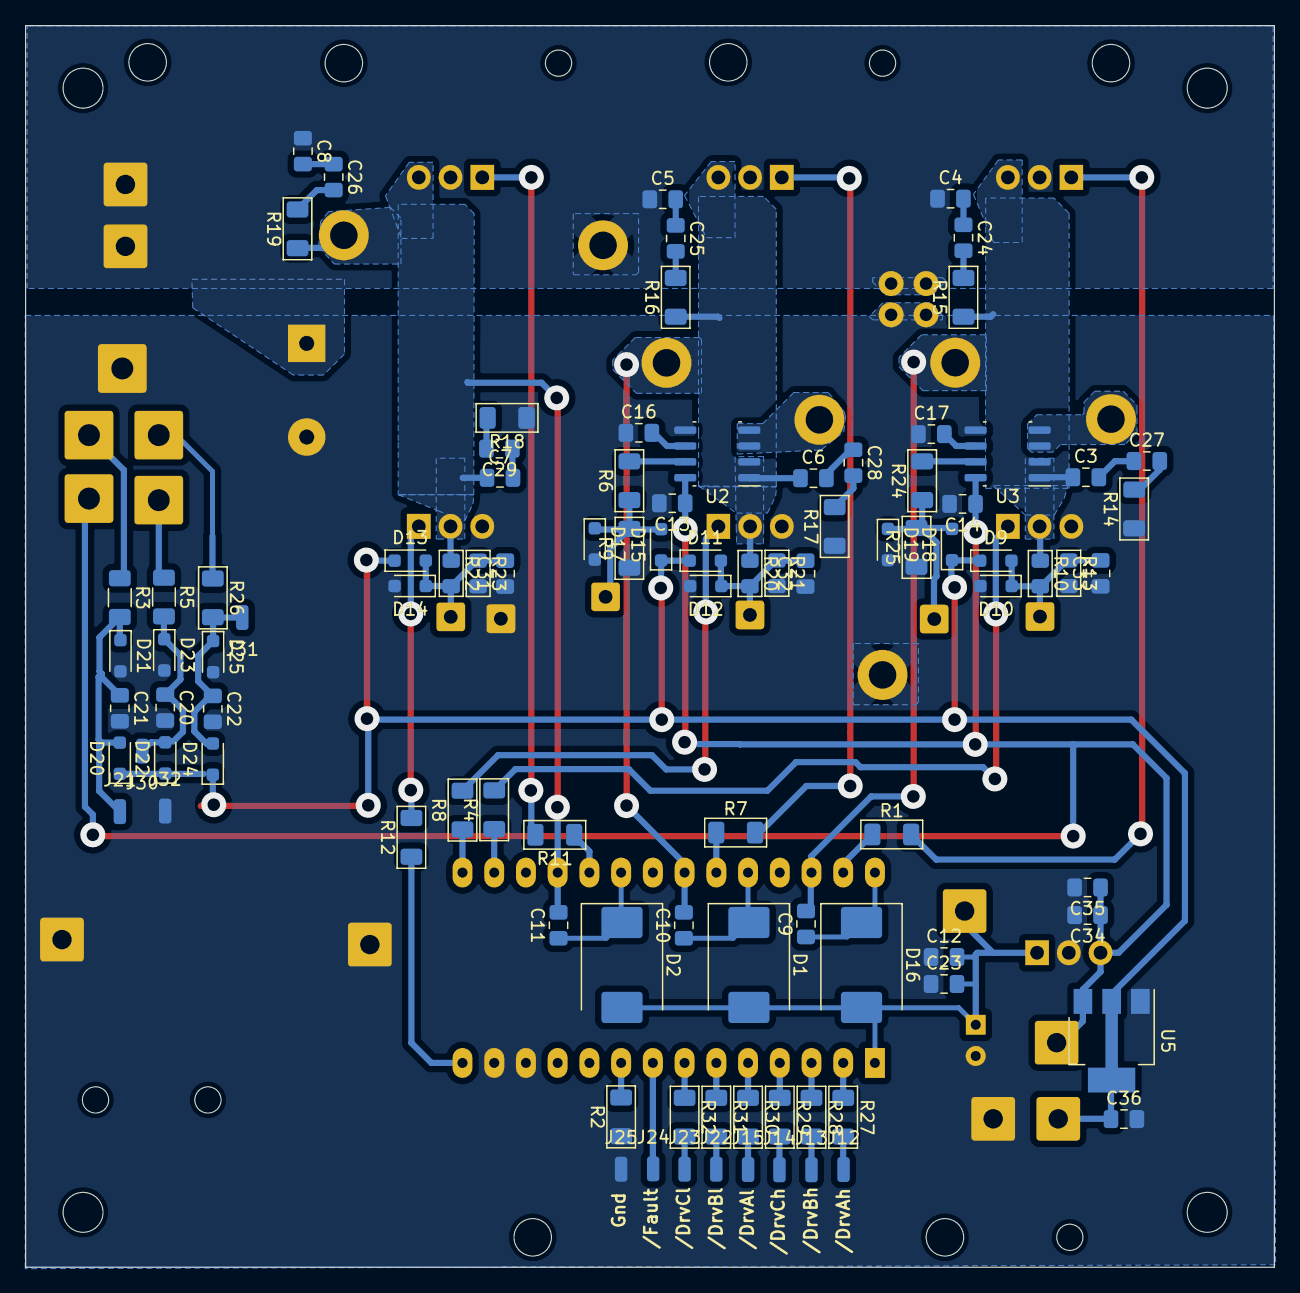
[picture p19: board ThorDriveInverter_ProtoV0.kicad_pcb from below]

Board: 2 copper layers, 100.0 x 99.4 mm, 128 parts (96 on the bottom side), 66 nets.

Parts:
+5V: SolderWire-1sqmm_1x01_D1.4mm_OD3.9mm
+12V: 15Vin; SolderWire-0.75sqmm_1x01_D1.25mm_OD3.5mm
Batt_GND: Bat Gnd; 12AWG cableSoldered
Batt_VCC: Bat VCC; 12AWG cableSoldered
C1: 470uF; CP_Radial_D18.0mm_P7.50mm
C2: 22uF; CP_Radial_D6.3mm_P2.50mm
C3, C4, C5, C6, C7, C8, C24, C25, C26, C27, C28, C29: 4.7nF; C_0805_2012Metric_Pad1.18x1.45mm_HandSolder
C9, C10, C11, C12, C34, C35, C36: 2.2uF; C_0805_2012Metric_Pad1.18x1.45mm_HandSolder
C13, C14, C23: 0.1uF; C_0805_2012Metric_Pad1.18x1.45mm_HandSolder
C15, C30: 2.2uF; C_Rect_L4.6mm_W2.0mm_P2.50mm_MKS02_FKP02
C16, C17, C31, C32, C33: 1nF; C_0805_2012Metric_Pad1.18x1.45mm_HandSolder
C20, C21, C22: 10nF; C_0805_2012Metric_Pad1.18x1.45mm_HandSolder
D1, D2, D16: SS310; D_SMC
D9, D10, D11, D12, D13, D14, D15, D17, D18, D19, D20, D21, D22, D23, D24, D25: SD103AWS; D_SOD-323_HandSoldering
Gnd: 15 Gnd; SolderWire-0.75sqmm_1x01_D1.25mm_OD3.5mm
Gnd#2: GND0_sense; SolderWire-0.5sqmm_1x01_D0.9mm_OD2.3mm
Hall_A: SolderWire-1sqmm_1x01_D1.4mm_OD3.9mm
Hall_C: SolderWire-1sqmm_1x01_D1.4mm_OD3.9mm
Hall_C#2: SolderWire-1sqmm_1x01_D1.4mm_OD3.9mm
Hall_Gnd: SolderWire-1sqmm_1x01_D1.4mm_OD3.9mm
J1: Motor_phaseA; 10mm2 CableSoldered
J2: Motor_phaseB; 10mm2 CableSoldered
J12, J13, J14, J15, J21, J22, J23, J24, J25, J30, J31, J32: SolderWirePad_1x01_SMD_1x2mm
PhA: Motor_phaseASensed; 10mm2 CableSoldered
PhA_Csense: PhaseA_Csense; SolderWire-0.5sqmm_1x01_D0.9mm_OD2.3mm
PhA_Vsense: PhaseA_Vsense; SolderWire-0.5sqmm_1x01_D0.9mm_OD2.3mm
PhB: Motor_phaseBSensed; 10mm2 CableSoldered
PhB_Csense: PhaseB_Csense; SolderWire-0.5sqmm_1x01_D0.9mm_OD2.3mm
PhB_Vsense: PhaseB_Vsense; SolderWire-0.5sqmm_1x01_D0.9mm_OD2.3mm
PhC: Motor_phaseC; 10mm2 CableSoldered
PhC_Vsense: PhaseC_Vsense; SolderWire-0.5sqmm_1x01_D0.9mm_OD2.3mm
Q1, Q2, Q3, Q4, Q5, Q6: IRF1407; TO-220-3_Vertical_GDS
R1, R4, R7, R8, R11, R12: 15; R_1206_3216Metric_Pad1.30x1.75mm_HandSolder
R2: 10k; R_1206_3216Metric_Pad1.30x1.75mm_HandSolder
R3, R5, R14, R15, R16, R17, R18, R19, R26: 100; R_1206_3216Metric_Pad1.30x1.75mm_HandSolder
R6, R24: 5K; R_1206_3216Metric_Pad1.30x1.75mm_HandSolder
R9, R25: 10K; R_1206_3216Metric_Pad1.30x1.75mm_HandSolder
R10, R20, R22: 47K; R_0805_2012Metric_Pad1.15x1.40mm_HandSolder
R13, R21, R23: 2.2k; R_0805_2012Metric_Pad1.15x1.40mm_HandSolder
R27, R28, R29, R30, R31, R32: 470; R_1206_3216Metric_Pad1.30x1.75mm_HandSolder
U1: IR2130PBF; DIP-28_W15.24mm_LongPads
U2, U3: ACS712ELCTR30AT; SOIC-8-1EP_3.9x4.9mm_P1.27mm_EP2.95x4.9mm_Mask2.71x3.4mm
U4: LM7805_TO220; TO-220-3_Vertical
U5: AMS1117-3.3; SOT-223-3_TabPin2

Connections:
+3.3V: C36.1, D9.1 (K), D11.1 (K), D13.1 (K), D15.1 (K), D18.1 (K), D20.1 (K), D22.1 (K), D24.1 (K), U5.2 (VO)
+5V: +5V.1, C13.1, C14.1, C34.1, C35.1, U2.8 (VCC), U3.8 (VCC), U4.3 (VO), U5.3 (VI)
+15V: +12V.1, C2.1, C12.2, C23.2, D1.2 (A), D2.2 (A), D16.2 (A), U1.1 (VCC), U4.1 (VI)
+BATT: Batt_VCC.1, C1.1, C4.1, C5.1, C8.1, C15.1, C30.1, Q1.2 (D), Q2.2 (D), Q3.2 (D)
/Connectors/HSensor1: Hall_C.1, R3.1
/Connectors/HSensor1_ToMCU: C21.1, D20.2 (A), D21.1 (K), J21.1, R3.2
/Connectors/HSensor2: Hall_C#2.1, R5.1
/Connectors/HSensor2_ToMCU: C20.1, D22.2 (A), D23.1 (K), J30.1, R5.2
/Connectors/HSensor3: Hall_A.1, R26.1
/Connectors/HSensor3_ToMCU: C22.1, D24.2 (A), D25.1 (K), J31.1, R26.2
GND: Batt_GND.1, C1.2, C2.2, C12.1, C13.2, C14.2, C15.2, C16.1, C17.1, C20.2, C21.2, C22.2, C23.1, C30.2, C31.1, C32.1, C33.1, C34.2, C35.2, C36.2, D10.2 (A), D12.2 (A), D14.2 (A), D17.2 (A), D19.2 (A), D21.2 (A), D23.2 (A), D25.2 (A), Gnd.1, Gnd#2.1, Hall_Gnd.1, J25.1, J32.1, Q4.3 (S), Q5.3 (S), Q6.3 (S), R2.1, R9.1, R13.2, R14.1, R17.1, R18.1, R21.2, R23.2, R25.1, U1.12 (VSS), U1.13 (VS0), U2.5 (GND), U3.5 (GND), U4.2 (GND), U5.1 (GND)
Isense_PhaseA: R24.2, U3.7 (VIOUT)
Isense_PhaseB: R6.2, U2.7 (VIOUT)
L1H: R1.1, U1.27 (HO1)
L1L: R4.1, U1.16 (LO1)
L2H: R7.1, U1.23 (HO2)
L2L: R8.1, U1.15 (LO2)
L3H: R11.1, U1.19 (HO3)
L3L: R12.1, U1.14 (LO3)
LOGIC_L1H: J12.1, R27.2
LOGIC_L1L: J15.1, R30.2
LOGIC_L2H: J13.1, R28.2
LOGIC_L2L: J22.1, R31.2
LOGIC_L3H: J14.1, R29.2
LOGIC_L3L: J23.1, R32.2
MCU_FAULT_IN (INPUT_PULLUP): J24.1, U1.8 (*FAULT)
unnamed: C4.2, C24.1
unnamed: C24.2, R15.2
unnamed: C5.2, C25.1
unnamed: C25.2, R16.2
unnamed: C8.2, C26.1
unnamed: C26.2, R19.2
unnamed: C3.2, C27.1
unnamed: C27.2, R14.2
unnamed: C6.2, C28.1
unnamed: C28.2, R17.2
unnamed: C7.2, C29.1
unnamed: C29.2, R18.2
unnamed: C33.2, D9.2 (A), D10.1 (K), PhA_Vsense.1, R10.2, R13.1
unnamed: C32.2, D11.2 (A), D12.1 (K), PhB_Vsense.1, R20.2, R21.1
unnamed: C31.2, D13.2 (A), D14.1 (K), PhC_Vsense.1, R22.2, R23.1
unnamed: D15.2 (A), D17.1 (K), PhB_Csense.1, R6.1, R9.2
unnamed: D18.2 (A), D19.1 (K), PhA_Csense.1, R24.1, R25.2
unnamed: Q1.1 (G), R1.2
unnamed: Q2.1 (G), R7.2
unnamed: Q3.1 (G), R11.2
unnamed: Q4.1 (G), R12.2
unnamed: Q5.1 (G), R8.2
unnamed: Q6.1 (G), R4.2
unnamed: R27.1, U1.2 (*HIN1)
unnamed: R28.1, U1.3 (*HIN2)
unnamed: R29.1, U1.4 (*HIN3)
unnamed: R30.1, U1.5 (*LIN1)
unnamed: R31.1, U1.6 (*LIN2)
unnamed: R32.1, U1.7 (*LIN3)
unnamed: R2.2, U1.9 (ITRIP)
unnamed: C16.2, U2.6 (FILTER)
unnamed: C17.2, U3.6 (FILTER)
PhaseA: C3.1, C9.2, J1.1, Q1.3 (S), Q6.2 (D), R10.1, R15.1, U1.26 (VS1), U3.1 (IP+), U3.2 (IP+)
PhaseA_Sensed: PhA.1, U3.3 (IP-), U3.4 (IP-)
PhaseB: C6.1, C10.2, J2.1, Q2.3 (S), Q5.2 (D), R16.1, R20.1, U1.22 (VS2), U2.1 (IP+), U2.2 (IP+)
PhaseB_Sensed: PhB.1, U2.3 (IP-), U2.4 (IP-)
PhaseC: C7.1, C11.2, PhC.1, Q3.3 (S), Q4.2 (D), R19.1, R22.1, U1.18 (VS3)
VBOOT1: C9.1, D16.1 (K), U1.28 (VB1)
VBOOT2: C10.1, D1.1 (K), U1.24 (VB2)
VBOOT3: C11.1, D2.1 (K), U1.20 (VB3)

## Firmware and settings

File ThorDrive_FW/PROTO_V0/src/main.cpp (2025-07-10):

/*
 * BLCD_FW.cpp
 *
 * Created: 6/21/2025 11:46:07 AM
 * Author : 20114
 */ 

#include "Config.h"
#include "module/System.h"
#include "core/softTimer.h"
#include "core/sys.h"
#include "util/delay.h"
#include "hal/hal.h"

#include <string.h>



int main(void)
{
    uartint_init(115200);
    sysTIM_init();
    System::Init();

    uint32_t t_ms = TICK_TO_mS(getTicks());
    UI::Ctrl_Led.setState(Led::State::On);
    char buffer[50];

    
    simpleTimer occ0;
    occ0.update(t_ms);

    simpleTimer occ1;
    occ1.update(t_ms);
    
    while (1) 
    {   
        t_ms = TICK_TO_mS(getTicks());
        occ0.update(t_ms);
        occ1.update(t_ms);

        if(occ0.checkTask(1000)){


        }

        if(occ1.checkTask(50)){
            System::Update(t_ms);
        }
    }
}

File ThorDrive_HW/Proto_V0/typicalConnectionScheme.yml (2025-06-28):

connectors:

###<INVERTER CONNECTORS AND CONNECTIONS>

#Inverter_toController
  Inverter_MosfetDriver_toController:
    type: JST XH-2.54 8-pin
    subtype: female
    pinlabels: [/MOS_Driver_Ah, /MOS_Driver_Bh, /MOS_Driver_Ch, /MOS_Driver_Al, /MOS_Driver_Bl, /MOS_Driver_Cl, /Fault, GND]
  Inverter_ElectricalFeedBack_toController:
    type: JST XH-2.54 6-pin
    subtype: female
    pinlabels: [Phase A Voltage, Phase A Current, Phase B Voltage, Phase B Current, Phase C Voltage, GND]
  Inverter_ConditionedHall_toController:
    type: JST XH-2.54 4-pin
    subtype: female
    pinlabels: [Hall_A, Hall_B, Hall_C, GND]
  Inverter_PowerSupply_toController:
      type: JST XH-2.54 3-pin
      subtype: female
      pinlabels: [5V, 3.3V, GND]
#Inverter_toMOTOR
  Inverter_MotorHall_toMotor:
    type: Molex 2Row 6-pin
    subtype: female
    pinlabels: [Hall_A, Hall_B, Hall_C, 5V, GND, NC]
  Inverter_MotorPhases_toMotor:
    type: Ring Terminal
    subtype: 3mm Ring
    pinlabels: [Phase_A, Phase_B, Phase_C]
#Inverter_toBattery
  Inverter_BatterySupply_toBattery:
    type: Ring Terminal
    subtype: 3mm Ring
    pinlabels: [Battery_VCC(24-60)V, Battery_GND]
#Inverter_toExtBuck
  Inverter_BuckSupply_toExtBuck:
    type: Jst XH-2.54 2-pin
    subtype: Male
    pinlabels: [12V, GND]


###<ExtBuck CONNECTORS AND CONNECTIONS>
  ExtBuck_BuckSupply_toInverter:
    type: Jst XH-2.54 2-pin
    subtype: Female
    pinlabels: [12V, GND]
  
  ExtBuck_BatterySupply_toBattery:
    type: Jst XH-2.54 2-pin
    subtype: Male
    pinlabels: [Battery_VCC(24-60)V, GND]


###<MOTOR CONNECTORS AND CONNECTIONS>
  Motor_MotorHall_toInverter:
    type: Molex 2Row 6-pin
    subtype: Male
    pinlabels: [Hall_A, Hall_B, Hall_C, 5V, GND, NC]
  
  Motor_MotorPhases_toInverter:
    type: Ring Terminal
    subtype: 3mm Ring
    pinlabels: [Phase_A, Phase_B, Phase_C]

###<BATTERY CONNECTORS AND CONNECTIONS>
  Battery_BatterySupply_toInverter:
    type: Ring Terminal
    subtype: 3mm Ring
    pinlabels: [Battery_VCC(24-60)V, Battery_GND]

  Battery_BatterySupply_toExtBuck:
    type: Jst XH-2.54 2-pin
    subtype: Female
    pinlabels: [Battery_VCC(24-60)V, GND]

###<CONTROLLER CONNECTORS AND CONNECTIONS>
  Controller_CondionedHall_toInverter:
    type: JST XH-2.54 4-pin
    subtype: PCB-Male
    pinlabels: [Hall_A, Hall_B, Hall_C, GND]

  Controller_MosfetDriver_toInverter:
    type: JST XH-2.54 8-pin
    subtype: PCB-Male
    pinlabels: [/MOS_Driver_Ah, /MOS_Driver_Bh, /MOS_Driver_Ch, /MOS_Driver_Al, /MOS_Driver_Bl, /MOS_Driver_Cl, /Fault, GND]
  
  Controller_PowerSupply_toInverter:
    type: JST XH-2.54 3-pin
    subtype: PCB-Male
    pinlabels: [5V, 3.3V, GND]
  
  Conteroller_ElectricalFeedBack_toInverter:
    type: JST XH-2.54 6-pin
    subtype: PCB-Male
    pinlabels: [Phase A Voltage, Phase A Current, Phase B Voltage, Phase B Current, Phase C Voltage, GND]

  Controller_ExternalButton_toController:
    type: JST XH-2.54 2-pin
    subtype: PCB-Male
    pinlabels: [ButtonSignal, 5V]

  Controller_ExternalPot_toController:
    type: JST XH-2.54 3-pin
    subtype: PCB-Male
    pinlabels: [5V, AnalogSingnal, GND]

  Controller_Uart_toController:
    type: Dupont-2.54 4-pin
    subtype: PCB-Male
    pinlabels: [GND, 5V, RX, TX]

cables:
  Inverter_MotorHall_Cable:
    gauge: 0.25 mm2
    length: 30 cm
    color_code: DIN
    wirecount: 5
    shield: false
  
  Inverter_MotorPhases_Cable:
    gauge: 5 mm2
    length: 30 cm
    color_code: DIN
    wirecount: 3
    shield: false

  Inverter_BatterySupply_Cable:
    gauge: 5 mm2
    length: 30 cm
    color_code: DIN
    wirecount: 2
    shield: false



connections:
-
  - Inverter_MosfetDriver_toController: [1-8]
  - <==>
  - Controller_MosfetDriver_toInverter: [1-8]
- 
  - Inverter_ConditionedHall_toController: [1-4]
  - <==
  - Controller_CondionedHall_toInverter: [1-4]
-
  - Inverter_PowerSupply_toController:  [1-3]
  - ==>
  - Controller_PowerSupply_toInverter: [1-3]
-
  - Controller_ExternalButton_toController:
-
  - Controller_ExternalPot_toController:
-
  - Controller_Uart_toController:
-
  - Inverter_ElectricalFeedBack_toController: [1:5]
  - <==
  - Conteroller_ElectricalFeedBack_toInverter: [1:5]
-
  - Inverter_MotorHall_toMotor: [1-5]
  - <==>
  - Motor_MotorHall_toInverter: [1-5]
-
  - Inverter_MotorPhases_toMotor: [1-3]
  - -->
  - Motor_MotorPhases_toInverter: [1-3]
-
  - Inverter_BatterySupply_toBattery: [1,2]
  - <--
  - Battery_BatterySupply_toInverter: [1,2]
-
  - Inverter_BuckSupply_toExtBuck: [1,2]
  - <--
  - ExtBuck_BuckSupply_toInverter: [1,2]
-
  - ExtBuck_BatterySupply_toBattery: [1,2]
  - <--
  - Battery_BatterySupply_toExtBuck: [1,2]
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

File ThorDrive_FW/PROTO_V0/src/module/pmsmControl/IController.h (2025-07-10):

#pragma once

#include "Config.h"
#include <stdint.h>
#include <string.h>
#include <stdio.h>
#include <inttypes.h>
#include "Hall/Hall.hpp"
#include "HBridge/HBridge.hpp"

namespace pmsmControl{
    
    enum class Direction : bool{
        Forward = 1,    
        Backward = 0
    };

    template <typename T>
    struct FlagPack{
        T flagsPack;
        inline void set(uint8_t idx){flagsPack |= (1<<(idx) );};
        inline void clear(uint8_t idx){flagsPack &= ~(1<<(idx) );};
        inline bool read(uint8_t idx){return flagsPack & (1<<(idx) );}
    };

    enum class PrintMode{
        CBOR_BIN,
        TXT
    };
    

    using hall = HallSensor<0>;
    using hBridgeDriver = HBridgeDriver<0>;


    class IController{ 
        public:
        
        struct Config{
            // Add your config methods/data here
            protected:
                friend class TrapezoidalController;
                friend class IController;
                uint16_t effDuty_UQ16;

            public:
                float effDuty_float;
                Direction direction;
                uint8_t polePairs;
                uint16_t switching_freq;
                float MaxDuty;
                float MinDuty;

            Config(){
                effDuty_float = 0;
                direction = Direction::Forward;
                polePairs = 2;
                switching_freq = 10000;
                MaxDuty = 0.95;
                MinDuty = 0.05;
            }
        };

        struct ConfigFeedback : public FlagPack<uint8_t>{
            enum Bit: uint8_t{
                isOk = 0,
                isOverFreq = 1,
                isUnderFreq = 2,
                isOverDuty = 3,
                isUnderDuty = 4,
            };

            ConfigFeedback(){
                set(isOk);
                clear(isOverFreq);
                clear(isOverDuty);
                clear(isUnderFreq);
                clear(isUnderDuty);
            }
        };

        struct State{
            struct stateFlags : public FlagPack<uint8_t>{
                enum Bit: uint8_t{
                    hardFault = 0,
                    running = 1,
                    startFail = 2,
                    hallConnected = 3,
                    overCurrent = 4,
                };
            }flags;
            float angle_rad;
            float angularVelocity_radPERs;

            State(){
                flags.clear(stateFlags::hardFault);
                flags.clear(stateFlags::running);
                flags.clear(stateFlags::startFail);
                flags.set(stateFlags::hallConnected);
                flags.clear(stateFlags::overCurrent);
                angle_rad = 0;
                angularVelocity_radPERs = 0;
            };
        };

        virtual ~IController() = default;
        virtual bool Init();
        virtual void Update(uint32_t t_ms);

        const State& GetState(){return state;};
        virtual const void* GetStateAdv_R();

        const Config& GetConfig(){return config;}
        virtual ConfigFeedback SetConfig(Config& cfg);

        bool PrintState(char* buffer, uint8_t size, PrintMode mode);
        bool PrintConfig(char* buffer, uint8_t size, PrintMode mode);
        virtual bool PrintStateAdv(char* buffer, uint8_t size, PrintMode mode);
    
    protected:
        constexpr uint16_t float_to_UQ16(float val){return static_cast<uint16_t>(val * 0xFFFF);};
        constexpr float UQ16_to_float(uint16_t val){return static_cast<float>(float(val) / 0xFFFF);}

        inline static Config config = Config();
        inline static State state = State();
        uint32_t updateTimeLast_ms = 0;    
        //Messages
        static constexpr const char* PrintState_txt = "<State:{F=%X A=%" PRId32 " AV=%" PRId32 "}>";
        static constexpr const char* PrintConfig_txt = "<Config:{D=%" PRIu16 " DIR=%c P=%" PRIu8 " SWF=%" PRIu16 "}>"; 
        // Protected constructor ensures only derived classes can instantiate
        IController() = default;
        /********************End of Interface structure IController (Any other controller variant for pmsm should inherit from it) *******************/
    };

    /*************END OF pmsmControl Namespace ******************************/
};

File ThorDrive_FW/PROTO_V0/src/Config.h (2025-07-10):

//Serial Port
#define SerialBaud 115200
#define SYSTEM_TICK_HZ 100



//3Phase MOSFET DRIVER (Inverted LOGIC)

#define DRIVER_Ah_PinNum 2
#define DRIVER_Ah_INVERT false

#define DRIVER_Bh_PinNum 3
#define DRIVER_Bh_INVERT false

#define DRIVER_Ch_PinNum 4
#define DRIVER_Ch_INVERT false

#define DRIVER_Al_PinNum 5
#define DRIVER_Al_INVERT true

#define DRIVER_Bl_PinNum 6
#define DRIVER_Bl_INVERT true

#define DRIVER_Cl_PinNum 7
#define DRIVER_Cl_INVERT true


//SPEED CONTROL (PWM) NANED with High side pins
#define SPEED_PinNum 10
#define SPEED_INVERT false

#define HALL_A_PinNum 8
#define HALL_A_INVERT true

#define HALL_B_PinNum 9
#define HALL_B_INVERT true

#define HALL_C_PinNum 11
#define HALL_C_INVERT true

//HALT_LED PIN 
#define CTRL_LED_PinNum 13
#define CTRL_LED_INVERT true

//CTRL_BTN PIN 
#define CTRL_BTN_PinNum 12
#define CTRL_BTN_INVERT false



//Controller Configuration
#define SWITCHING_FREQ 10000
#define accelleration_pps 2 //Accelleration in percentage per second (percentage from full speed) 
#define minSpeed_duty 0.05 //Minimum duty cycle percentage for the motor to start
#define maxSpeed_duty 0.9 //Maximum duty cycle percentage for the motor to run (Check bootstrap high side drive limits)
#define POLE_PAIRS 23

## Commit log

2025-06-15 Firmware and Hardware Initials
    [3phase Inverter BGA V0.1.kicad_pcb, 3phase Inverter BGA V0.1.kicad_sch, Signal Conditioning.kicad_sch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]
2025-06-16 Routing Try0
    [Signal Conditioning.kicad_sch, ThorDrive_HW.kicad_pcb, ThorDrive_HW.kicad_sch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]
2025-06-16 Controller Board V0 Finalized
    A Controller Board simple and built upon the Atmega328p...
    Single Layer Design with few jumpers.... Compatible with Inverter V0
    [Signal Conditioning.kicad_sch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]
2025-06-16 Added GPIO struct and Modified PWM driver
2025-06-19 Latest hardware changes (added pulldown Resistor for CTRL button)
    [ThorDrive_HW.kicad_pcb]
2025-06-22 Added Basic Drivers, Initialized system manager
    [ThorDrive_HW.kicad_pcb, ThorDrive_HW.kicad_sch]
2025-06-28 Added Hardware Documentation and reference Designs..... Added Software template and multiple modules
    [3phase Inverter BGA V0.1.kicad_pcb, 3phase Inverter BGA V0.1.kicad_sch, POT.stp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]
